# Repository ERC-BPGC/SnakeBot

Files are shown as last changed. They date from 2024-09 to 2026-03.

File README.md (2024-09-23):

# Project SnakeBot

### Overview 

SnakeBot is a modular, wheelless robot designed by the students of Electronics and Robotics Club. It uses a series of universal joints that provide 2 degrees of freedom (DOF) at each joint. The robot is actuated with the help of strings connected to servos, which rotate each module independently in its plane.

Our project aims to explore the locomotion patterns of snakes and apply them to robotics. Initially, we are focusing on straight-line motion and navigating in the 2D plane, but we aim to implement more advanced movements in the future, such as:

- Serpentine motion
- Sidewinding motion
- Lateral motion (Barell Roll)

The long-term goal of this project is to use the frictional properties of custom designed skin, allowing it to traverse various terrains and surfaces with minimal energy loss, just like biological snakes.

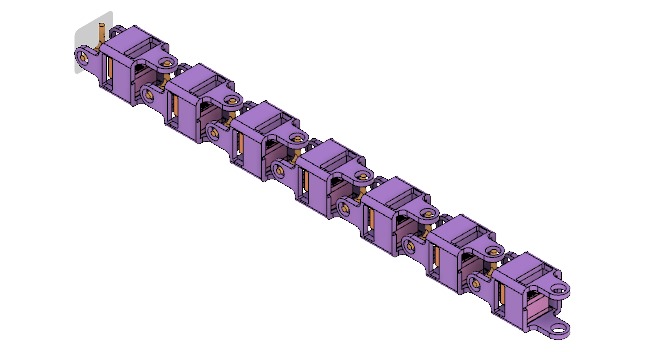
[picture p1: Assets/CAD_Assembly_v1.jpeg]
CAD Assembly


### Motion

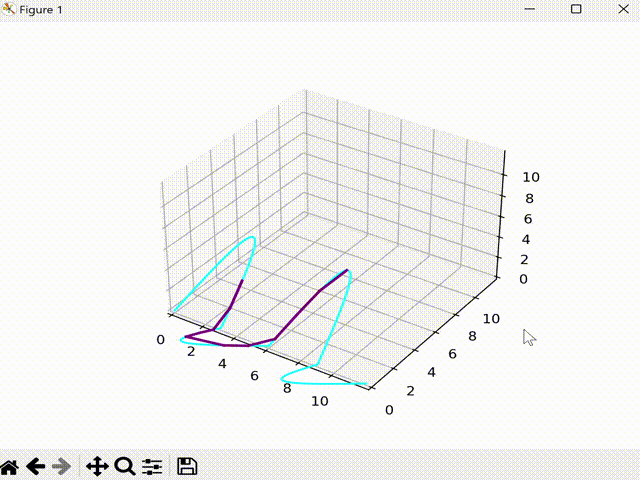
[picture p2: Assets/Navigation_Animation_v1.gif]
Modular motion in single axis


The fundamental concept behind this is using a sinosoidal wave in the x-y and y-z planes (phase shifted and one wave's amplitude encompassing another wave's) and then fitting the modular snakebot links within the bounds of this wave. This allows it to traverse in any direction based on how the wave evolves.

### PCB Designing

To give full modularity to the robot we have developed a modular, chainable PCB based on the RP2040 microcontroller. Each modular PCB consists of a power management circuit, LiPo battery connection, ability to add sensors like an IMU (MPU-6050), and controlling 2 servo motors per each module. We are planning to use serial communication between each module.

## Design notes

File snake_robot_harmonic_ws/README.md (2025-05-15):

# 🐍 Snake Robot MuJoCo Simulation Walkthrough

This guide provides a step-by-step walkthrough for setting up and running the **MuJoCo-based simulation** of a snake robot, located in your `snake_robot_harmonic_ws` workspace. This simulation is **standalone**—it does **not use ROS or Gazebo**—and is implemented purely using **MuJoCo and Python**.

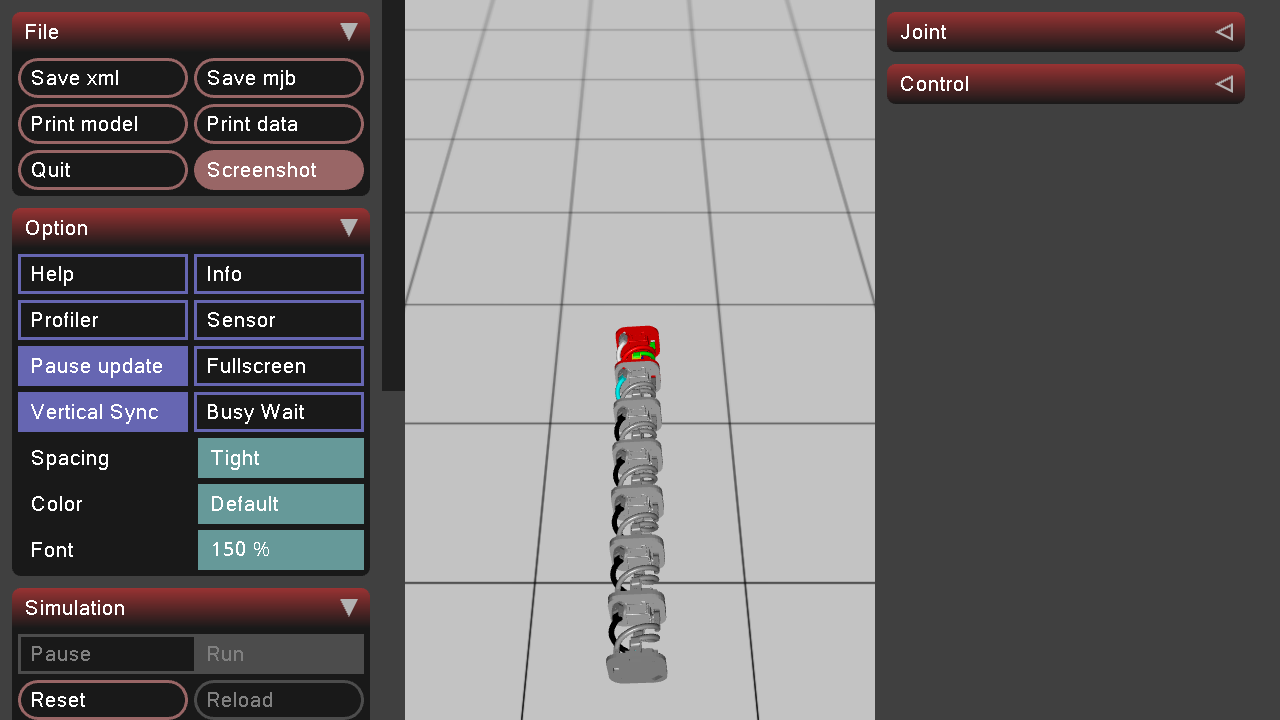
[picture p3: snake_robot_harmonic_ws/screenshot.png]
Snake Robot Model

---

## 📁 Project Structure Overview

```
snake_robot_harmonic_ws/
├── src/
│   └── SnakeBot/
│       ├── meshes/                                # STL files for the robot model
│       ├── ModelV2.xml                            # MuJoCo model of the snake robot
│       ├── scene.xml                              # MuJoCo scene (includes the robot and environment)
│       ├── nileshcode.py                          # Opens the MuJoCo model (no movement)
│       ├── multi_neuron_cpg_control.py            # Controller implementation (based on research)
│       ├── FLEXER_CPG_Sinusoidal_Control_Snake_Robot_Locomotion.py  # Another controller (FLEXER)
│       └── ...                                     # Other scripts and files
├── requirements.txt                                # Python dependencies
```

---

## 🧪 Setting Up the Python Virtual Environment

To ensure a clean and consistent development environment, we recommend using a virtual environment.

### Step 1: Navigate to the workspace

```bash
cd ~/snake_robot_harmonic_ws
```

### Step 2: Create and activate the virtual environment

```bash
python3 -m venv mujoco_env
source mujoco_env/bin/activate
```

> 💡 **Windows users**: Use `mujoco_env\Scripts\activate` instead.

### Step 3: Install required Python packages

Install dependencies listed in `requirements.txt`.  

> ⚠️ **Note**: This file may contain extra packages (e.g. ROS, CUDA, reinforcement learning libraries).  
> You can manually edit it to keep only the relevant packages for MuJoCo if needed.

```bash
pip install -r requirements.txt
```

---

## 🚀 Running the Simulation

After activating the virtual environment, you can run any of the following simulation scripts.

> ✅ **Important**: Make sure you're using the Python interpreter from the virtual environment.  
> If you're using an IDE or script launcher, confirm it uses the correct interpreter path.  
> You can also run scripts explicitly using the full path to the environment's Python:

```bash
./mujoco_env/bin/python path/to/script.py
```

### A. Launch MuJoCo Viewer (No Movement)

Opens the simulation in MuJoCo with the robot model loaded.

```bash
python src/SnakeBot/nileshcode.py
```

### B. Run Multi-Neuron CPG Controller

Based on a central pattern generator (CPG) research model.

```bash
python src/SnakeBot/multi_neuron_cpg_control.py
```
### 🧠 Multi-Neuron CPG Controller (Simulation)

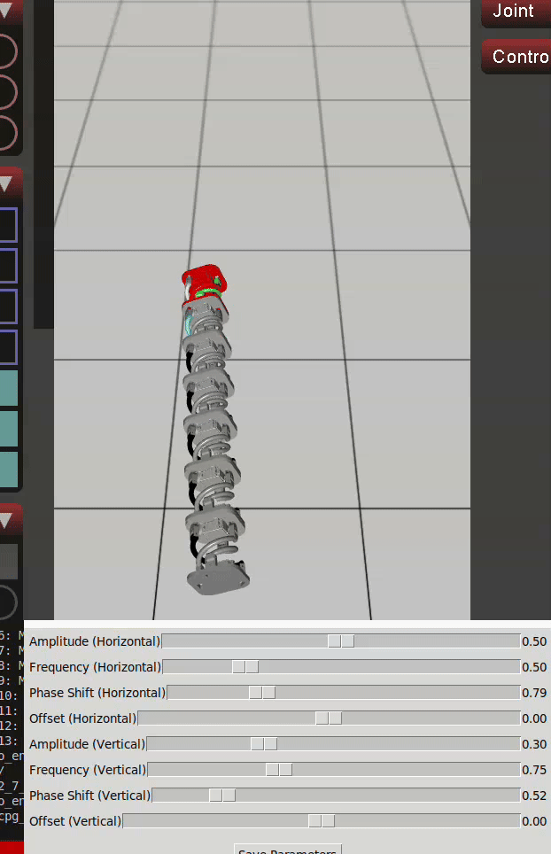
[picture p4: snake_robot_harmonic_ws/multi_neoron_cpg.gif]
Multi Neuron CPG Demo


### C. Run FLEXER CPG Sinusoidal Controller

Another research-based controller using FLEXER and sinusoidal inputs.

```bash
python src/SnakeBot/FLEXER_CPG_Sinusoidal_Control_Snake_Robot_Locomotion.py
```

### 🌊 FLEXER CPG Sinusoidal Controller (Simulation)

FLEXER CPG Demo
---

## 🧩 Notes and Recommendations

- ✅ Ensure that `scene.xml` and `ModelV2.xml` correctly reference STL files from the `meshes/` folder.
- 🧠 The control scripts implement algorithms from published research papers. You can customize the control parameters or logic for further experimentation.
- 💾 Consider creating a cleaned version of `requirements.txt` by running:

  ```bash
  pip freeze > requirements_clean.txt
  ```

---

## 📌 Summary

| Step | Description |
|---|---|
| ✅ 1 | Create & activate the `mujoco_env` virtual environment |
| ✅ 2 | Install dependencies from `requirements.txt` |
| ✅ 3 | Run desired control script (`nileshcode`, `multi_neuron_cpg_control`, or `FLEXER...`) |
| ✅ 4 | **Ensure you're using the correct Python interpreter from the virtual environment** (use full path if needed) |
| ✅ 5 | Validate STL and XML references for simulation correctness |

---

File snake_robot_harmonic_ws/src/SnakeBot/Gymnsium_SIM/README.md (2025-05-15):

Snake Robot Simulation Guide(Chatgpt for  simplification )

This is a guide for a Python program that makes a pretend snake robot move on your computer. It’s like a little game where the snake wiggles to move forward, and we see how good it is at moving. Let’s break it into tiny, easy bits!

What’s This Thing Do?

Imagine a toy snake made of blocks that can bend. This program:

Makes the snake wiggle like a real snake using wavy moves.

Runs little 10-second tests to see how far it goes.

Gives it points for moving forward fast.

Shows you pictures (graphs) of how well it did.

You can watch it wiggle in a window on your screen!

The Big Pieces

The program has 4 main parts—like ingredients in a recipe:

Tools (Imports): Stuff the program needs to work.

Snake World (SnakeEnv): Where the snake lives and moves.

Score Pictures (plot_rewards): Draws graphs of the snake’s points.

Start Button (main): Runs everything.

Let’s look at each one super simply.

1. Tools (Imports)

These are like helpers the program borrows:

gymnasium: Makes the pretend world.

MujocoEnv: Helps the snake move like it’s real.

numpy: Does math for us.

time: Slows things down so we can see.

matplotlib: Draws pictures of the scores.

2. Snake World (SnakeEnv)

This is the snake’s home. It’s split into little jobs.

Job lyk1: Starting Up (init)

Sets up the snake’s world.

Makes a big window (1280x720) to watch it.

Says the snake has 14 bendy parts (7 up-down, 7 side-side).

Keeps track of 41 things about the snake (like where it is and how fast it’s going).

Job 2: Looking at the Snake (_get_obs)

Takes a quick peek at the snake.

Writes down 41 numbers—like its spot, tilt, speed, and how its parts are bent.

Job 3: Moving a Tiny Bit (step)

Makes the snake wiggle once.

Picks wavy moves (like “big wiggle, fast wiggle”) using random numbers.

Example wiggle: “Bend up a little, then down, fast!”

Moves the snake a tiny step.

Checks if 10 seconds are up—if yes, it’s done.

Gives points for going forward.

Job 4: Starting Over (reset_model)

Puts the snake back to the start.

Picks new random wiggles for the next try.

Job 5: Picking Wiggles (_set_random_parameters)

Chooses random stuff for the wiggles:

How big the wiggle is.

How fast it wiggles.

Where the wiggle starts.

It’s like saying, “Wiggle big and slow this time!”

3. Score Pictures (plot_rewards)

Draws 2 pictures:

One shows all the points from each 10-second test.

One shows points for every tiny move in the last test.

Saves them as total_rewards_plot.png and last_episode_rewards_plot.png.

4. Start Button (main)

Turns on the snake world.

Keeps it going:

Moves the snake tiny bits.

Counts points.

After 10 seconds, starts over with new wiggles.

Prints stuff like “Episode 1: 50 points!”

When you stop it (close the window), it shows the pictures.

How It Works, Step by Step

Start: The program loads the snake and opens a window.

Wiggle: The snake moves with random wiggles for 10 seconds.

Score: It gets points for going forward.

Repeat: Starts over with new wiggles.

Finish: You close it, and it shows score pictures.

Easy Example

Think of the snake like a toy car with bendy parts:

You push “start,” and it wiggles forward.

If it goes far, it gets lots of points!

Every 10 seconds, you try a new wiggle to see if it’s better.

How to Play With It

Get Ready: Make sure you have the tools (like gymnasium) on your computer.

Find the Snake: Tell the program where the snake’s file is.

Run It: Start the program—watch the snake wiggle!

Stop It: Close the window when you’re done.

See Scores: Look at the pictures it saves.

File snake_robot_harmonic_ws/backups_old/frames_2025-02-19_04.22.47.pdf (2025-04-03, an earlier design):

view_frames Result

Recorded at time: 1739919167.9612372

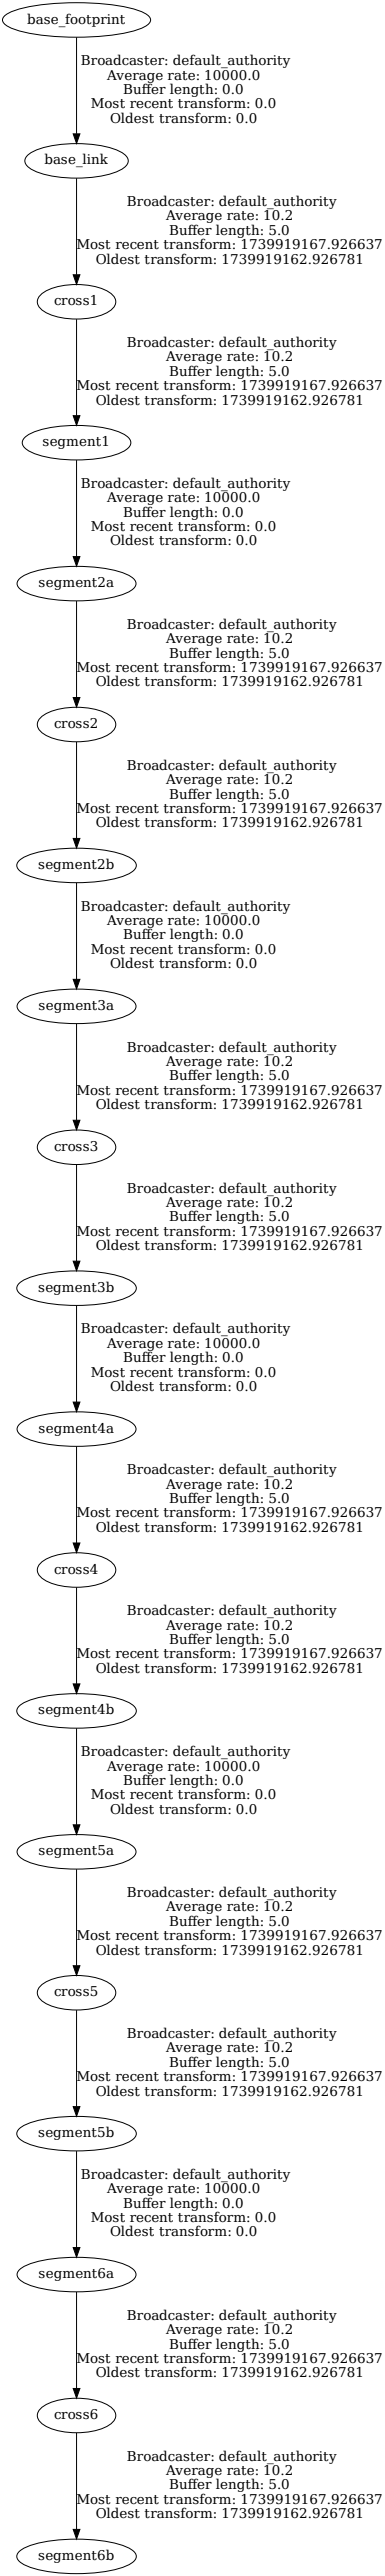
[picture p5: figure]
cross1; segment1; Broadcaster: default_authority Average rate: 10.2 Buffer length: 5.0 Most recent transform: 1739919167.926637 Oldest transform: 1739919162.926781; segment2a; Broadcaster: default_authority Average rate: 10000.0 Buffer length: 0.0 Most recent transform: 0.0 Oldest transform: 0.0; base_link; segment5a; cross5; segment5b; segment4b; cross6; segment6b; segment6a; base_footprint; cross2; segment2b; segment3a; cross3; segment3b; segment4a; cross4

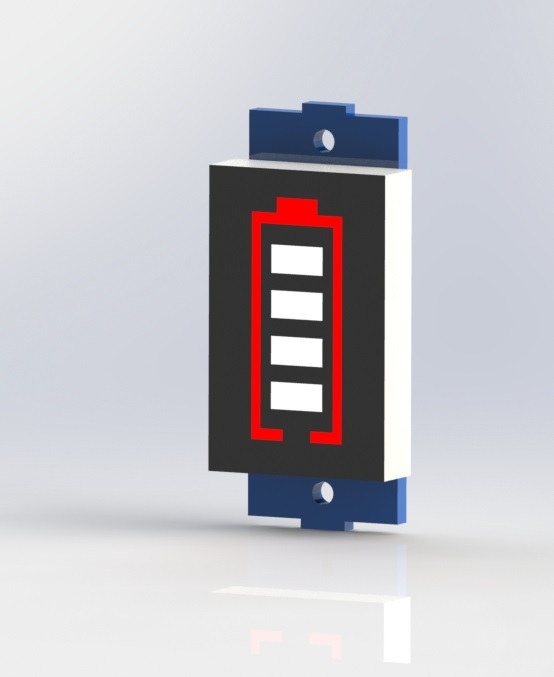
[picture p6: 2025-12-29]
mech/new/18650-li-ion-battery-capacity-indicator-module-1.snapshot.1/Lithium Battery Capacity Indicator Module/Lithium Battery Capacity Indicator Module.JPG

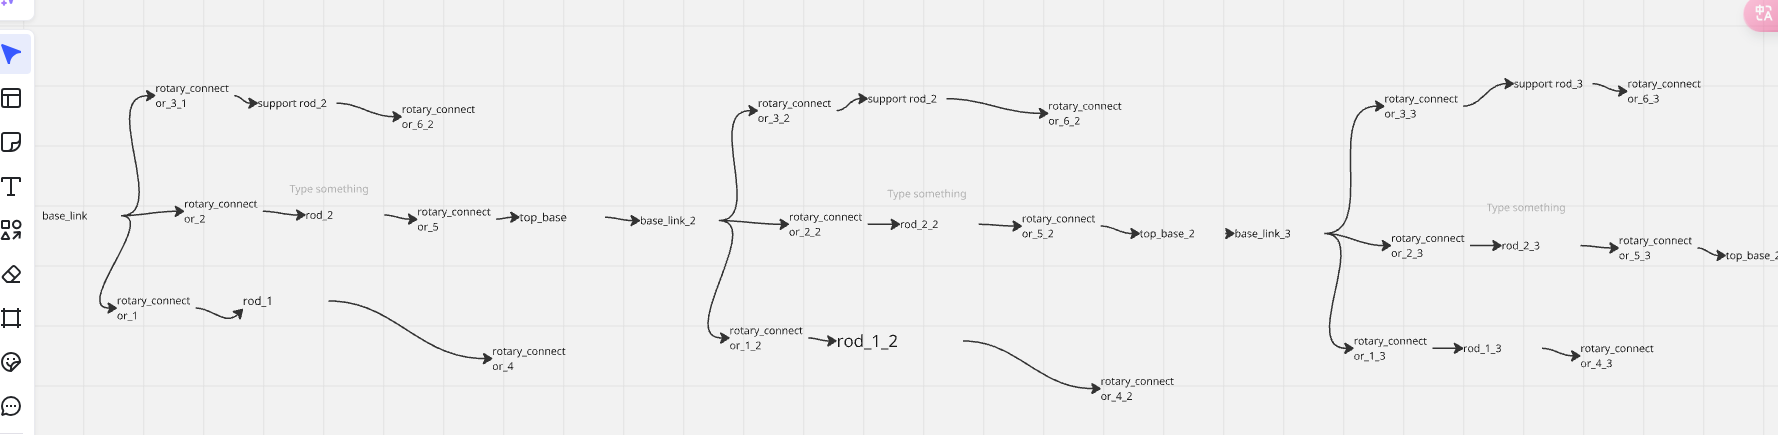
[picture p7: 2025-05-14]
snake_robot_harmonic_ws/src/SnakeBot/Gymnsium_SIM _backup_working_basic/my_env/robot_model/meshes/Opera Snapshot_2025-04-20_045715_miro.com.png

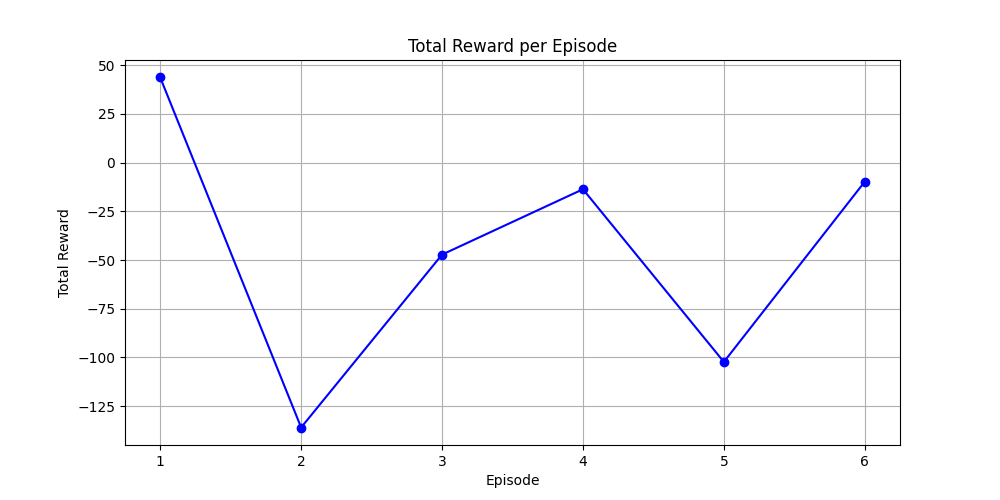
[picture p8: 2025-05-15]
snake_robot_harmonic_ws/src/SnakeBot/Gymnsium_SIM/my_env/total_rewards_plot.png

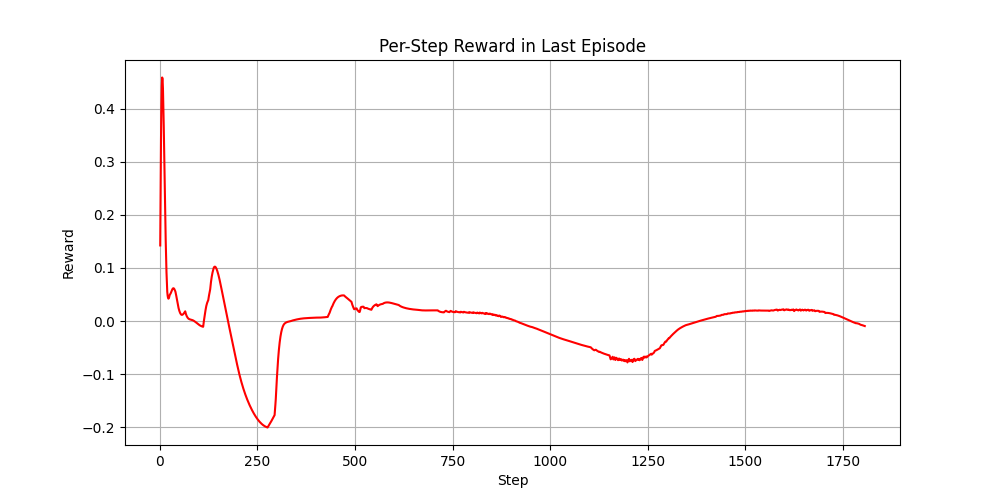
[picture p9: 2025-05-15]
snake_robot_harmonic_ws/src/SnakeBot/Gymnsium_SIM/my_env/last_episode_rewards_plot.png

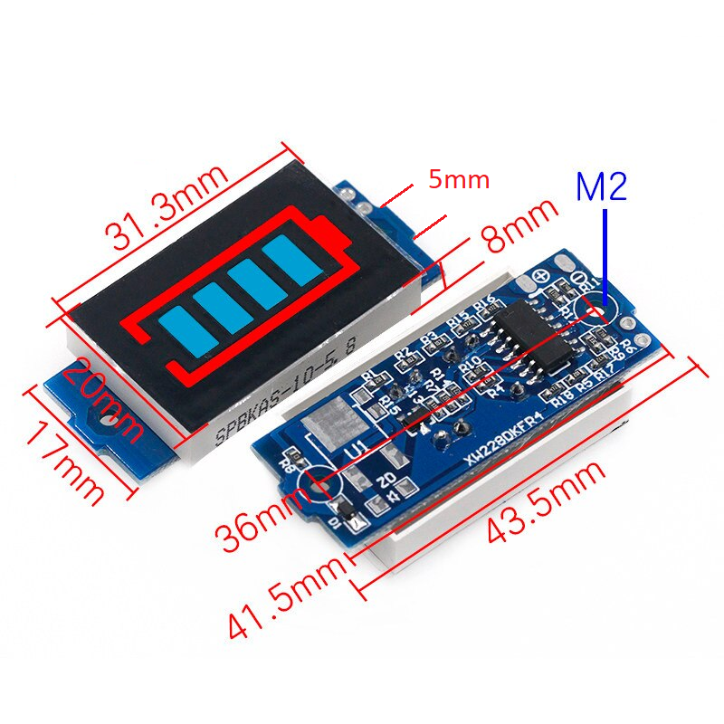
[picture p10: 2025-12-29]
mech/new/18650-li-ion-battery-capacity-indicator-module-1.snapshot.1/Lithium Battery Capacity Indicator Module/Lithium Battery Capacity Indicator Module dimentions.png

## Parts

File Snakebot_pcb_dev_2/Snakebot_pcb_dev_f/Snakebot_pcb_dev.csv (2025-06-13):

Reference | Value | Datasheet | Footprint | Qty | DNP
C1 | 22uF | ~ | Capacitor_SMD:C_0603_1608Metric_Pad1.08x0.95mm_HandSolder | 1
C2 | 0.1uF | ~ | Capacitor_SMD:C_0603_1608Metric_Pad1.08x0.95mm_HandSolder | 1
C3 | 1uF | ~ | Capacitor_SMD:C_0805_2012Metric_Pad1.18x1.45mm_HandSolder | 1
C4 | 10uF | ~ | Capacitor_SMD:C_0805_2012Metric_Pad1.18x1.45mm_HandSolder | 1
C5 | 10uF | ~ | Capacitor_SMD:C_0805_2012Metric_Pad1.18x1.45mm_HandSolder | 1
C6 | 0.1uF | ~ | Capacitor_SMD:C_0603_1608Metric_Pad1.08x0.95mm_HandSolder | 1
C7 | 0.1uF | ~ | Capacitor_SMD:C_0603_1608Metric_Pad1.08x0.95mm_HandSolder | 1
C8 | 22uF | ~ | Capacitor_SMD:C_0603_1608Metric_Pad1.08x0.95mm_HandSolder | 1
C9 | 0.1uF | ~ | Capacitor_SMD:C_0603_1608Metric_Pad1.08x0.95mm_HandSolder | 1
C10 | 22uF | ~ | Capacitor_SMD:C_0603_1608Metric_Pad1.08x0.95mm_HandSolder | 1
C11 | 1uF | ~ | Capacitor_SMD:C_0805_2012Metric_Pad1.18x1.45mm_HandSolder | 1
C12 | 1uF | ~ | Capacitor_SMD:C_0805_2012Metric_Pad1.18x1.45mm_HandSolder | 1
C13 | 0.1uF | ~ | Capacitor_SMD:C_0603_1608Metric_Pad1.08x0.95mm_HandSolder | 1
C14 | 0.1uF | ~ | Capacitor_SMD:C_0603_1608Metric_Pad1.08x0.95mm_HandSolder | 1
C15 | 0.1uF | ~ | Capacitor_SMD:C_0603_1608Metric_Pad1.08x0.95mm_HandSolder | 1
C16 | 220pF | ~ | Capacitor_SMD:C_0603_1608Metric_Pad1.08x0.95mm_HandSolder | 1
D1 | LED | ~ | LED_SMD:LED_0805_2012Metric_Pad1.15x1.40mm_HandSolder | 1
D2 | LED | ~ | LED_SMD:LED_0805_2012Metric_Pad1.15x1.40mm_HandSolder | 1
D3 | LED | ~ | LED_SMD:LED_0805_2012Metric_Pad1.15x1.40mm_HandSolder | 1
J1 | Conn_01x04_Socket | ~ | Connector_JST:JST_EH_S4B-EH_1x04_P2.50mm_Horizontal | 1
J2 | Conn_01x02_Socket | ~ | Connector_JST:JST_EH_S2B-EH_1x02_P2.50mm_Horizontal | 1
J3 | Conn_01x03_Socket | ~ | Connector_JST:JST_EH_B3B-EH-A_1x03_P2.50mm_Vertical | 1
J4 | Conn_01x03_Socket | ~ | Connector_JST:JST_EH_B3B-EH-A_1x03_P2.50mm_Vertical | 1
J5 | Conn_01x02_Socket | ~ | Connector_JST:JST_EH_S2B-EH_1x02_P2.50mm_Horizontal | 1
J6 | Conn_01x02_Socket | ~ | Connector_JST:JST_EH_S2B-EH_1x02_P2.50mm_Horizontal | 1
J7 | Conn_01x08_Socket | ~ | Connector_JST:JST_EH_B8B-EH-A_1x08_P2.50mm_Vertical | 1
J8 | Conn_01x08_Socket | ~ | Connector_JST:JST_EH_B8B-EH-A_1x08_P2.50mm_Vertical | 1
L1 | 6.8uH | ~ | Inductor_SMD:L_Bourns_SRN8040TA | 1
R1 | 10k | ~ | Resistor_SMD:R_0603_1608Metric_Pad0.98x0.95mm_HandSolder | 1
R2 | 1K | ~ | Resistor_SMD:R_0603_1608Metric_Pad0.98x0.95mm_HandSolder | 1
R3 | 1K | ~ | Resistor_SMD:R_0603_1608Metric_Pad0.98x0.95mm_HandSolder | 1
R4 | 1K | ~ | Resistor_SMD:R_0603_1608Metric_Pad0.98x0.95mm_HandSolder | 1
R5 | 50m | ~ | Resistor_SMD:R_0603_1608Metric_Pad0.98x0.95mm_HandSolder | 1
R6 | 10k | ~ | Resistor_SMD:R_0603_1608Metric_Pad0.98x0.95mm_HandSolder | 1
R7 | 10k | ~ | Resistor_SMD:R_0603_1608Metric_Pad0.98x0.95mm_HandSolder | 1
R8 | 100k | ~ | Resistor_SMD:R_0805_2012Metric_Pad1.20x1.40mm_HandSolder | 1
R9 | 4.7k | ~ | Resistor_SMD:R_0603_1608Metric_Pad0.98x0.95mm_HandSolder | 1
R10 | 4.7k | ~ | Resistor_SMD:R_0603_1608Metric_Pad0.98x0.95mm_HandSolder | 1
SW1 | SW_Push | ~ | Button_Switch_SMD:SW_Push_1P1T_NO_CK_KSC6xxJ | 1
SW2 | SW_Push | ~ | Button_Switch_SMD:SW_Push_1P1T_NO_CK_KSC6xxJ | 1
SW3 | SW_SPDT | ~ | Button_Switch_SMD:SW_SPDT_CK_JS102011SAQN | 1
U1 | ESP32-WROOM-32E | https://www.espressif.com/sites/default/files/documentation/esp32-wroom-32e_esp32-wroom-32ue_datasheet_en.pdf | RF_Module:ESP32-WROOM-32D | 1
U2 | AMS1117-3.3 | http://www.advanced-monolithic.com/pdf/ds1117.pdf | Package_TO_SOT_SMD:SOT-223-3_TabPin2 | 1
U3 | MP2615GQ-P | MP2615GQ-P | MP2615:QFN-3x3_MP2615_MNP | 1
U4 | MPU-6050 | https://invensense.tdk.com/wp-content/uploads/2015/02/MPU-6000-Datasheet1.pdf | Sensor_Motion:InvenSense_QFN-24_4x4mm_P0.5mm | 1

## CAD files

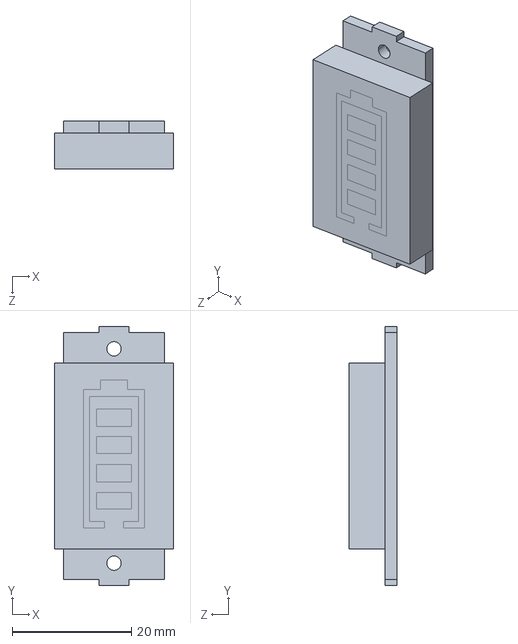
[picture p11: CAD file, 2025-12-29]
mech/new/18650-li-ion-battery-capacity-indicator-module-1.snapshot.1/Lithium Battery Capacity Indicator Module/Lithium Battery Capacity Indicator Module.STEP
20.0 x 43.5 x 8.00 mm

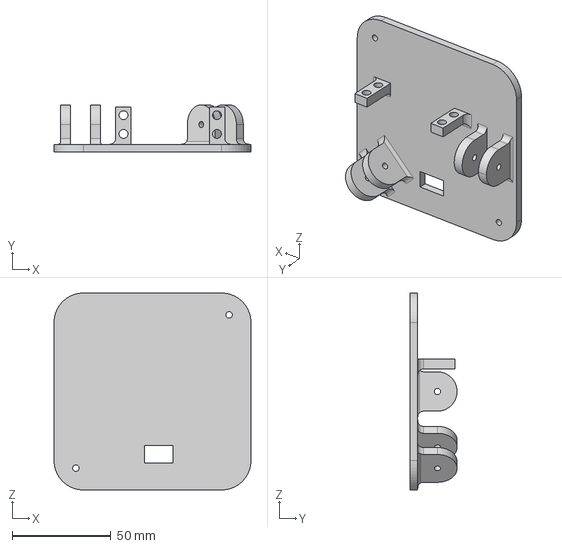
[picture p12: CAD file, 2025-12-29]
mech/new/Component1.step
100.0 x 24.0 x 100.0 mm

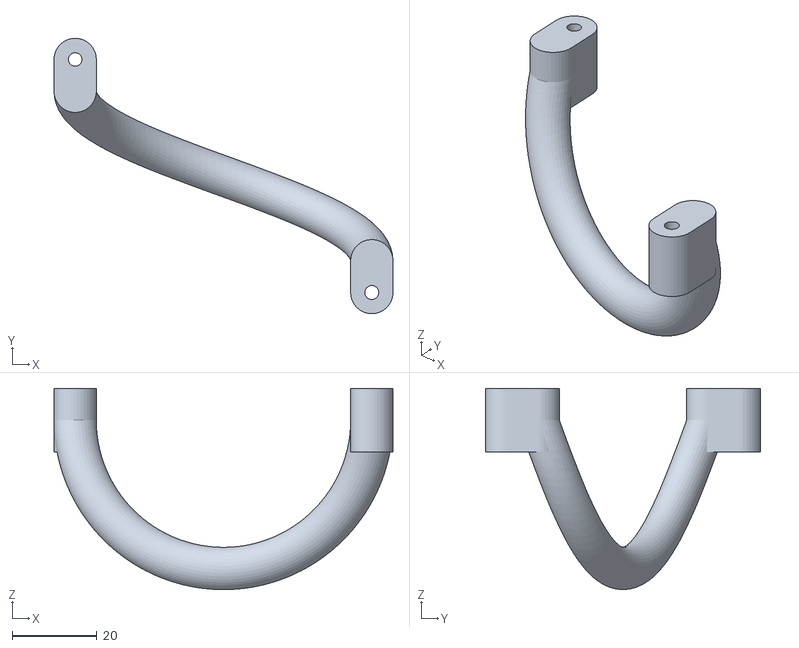
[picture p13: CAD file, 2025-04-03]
snake_robot_harmonic_ws/src/ros_gz_example_description/models/snakebot/meshes/rod.stl
80.0 x 65.0 x 47.5

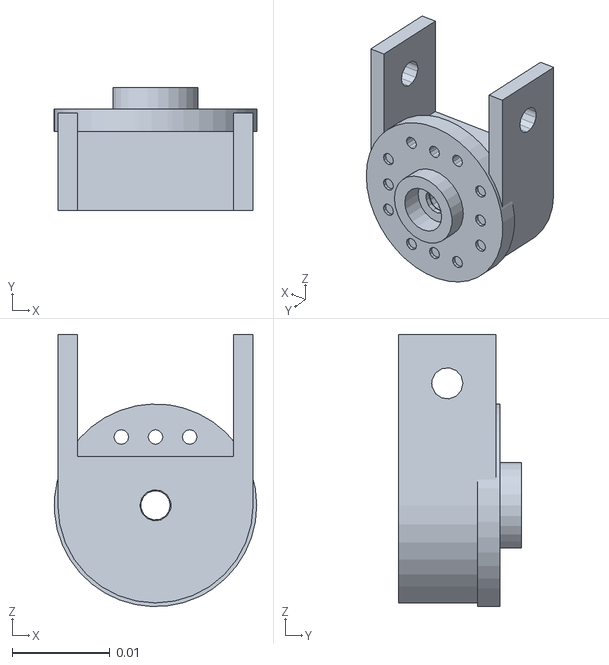
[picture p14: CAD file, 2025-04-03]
snake_robot_harmonic_ws/src/SnakeBot/Gymnsium_SIM _backup_working_basic/my_env/robot_model/meshes/rotary_connector_1.STL
0.0207 x 0.0126 x 0.0279

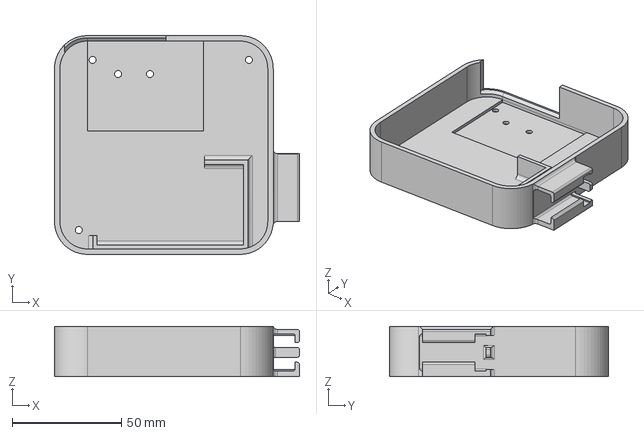
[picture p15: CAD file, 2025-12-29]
mech/new/dabba_sarn.step
112.0 x 100.0 x 23.0 mm

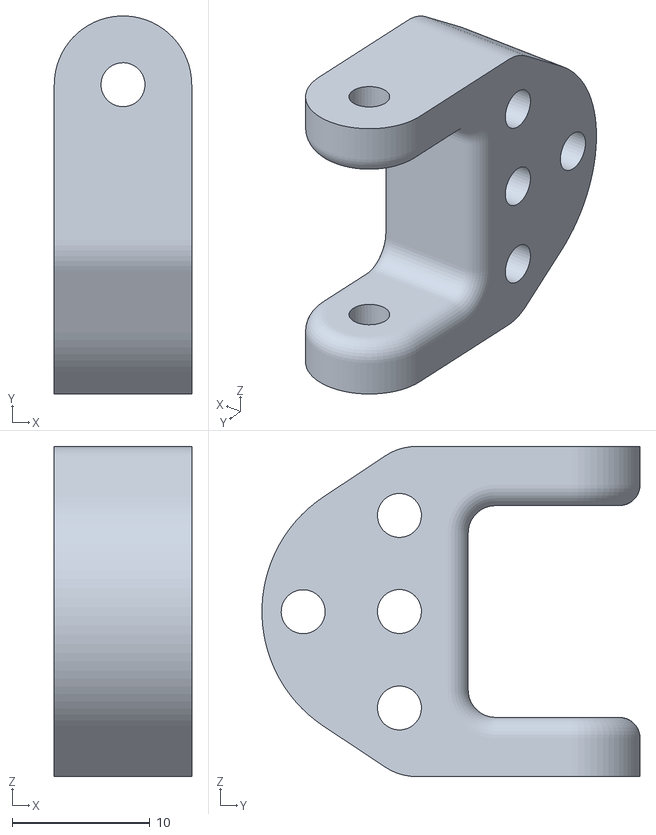
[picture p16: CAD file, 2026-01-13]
Mujoco/chintu.stl
10.0 x 27.5 x 24.0

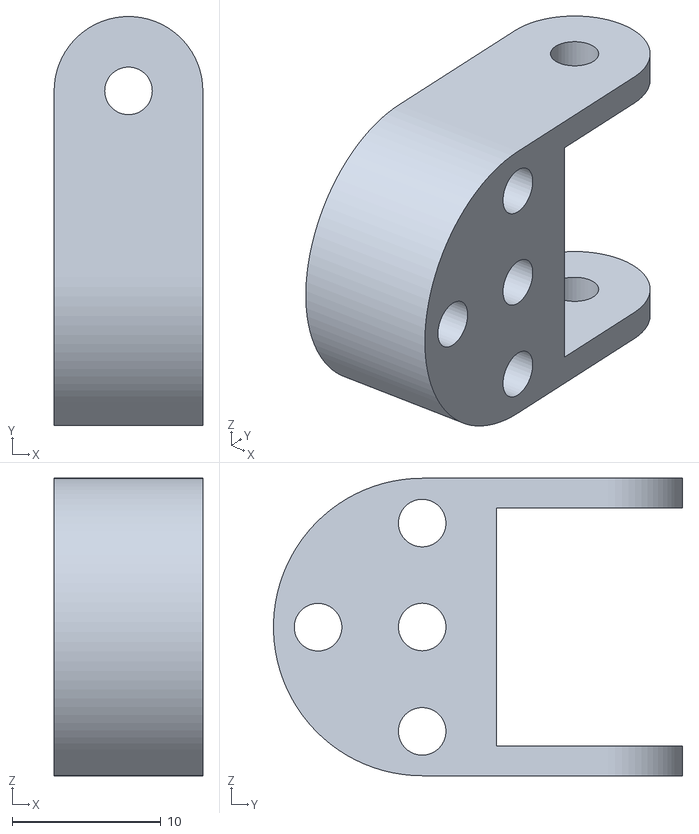
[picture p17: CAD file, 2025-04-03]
snake_robot_harmonic_ws/src/ros_gz_example_description/models/snakebot/meshes/rotary.stl
10.0 x 27.5 x 20.0

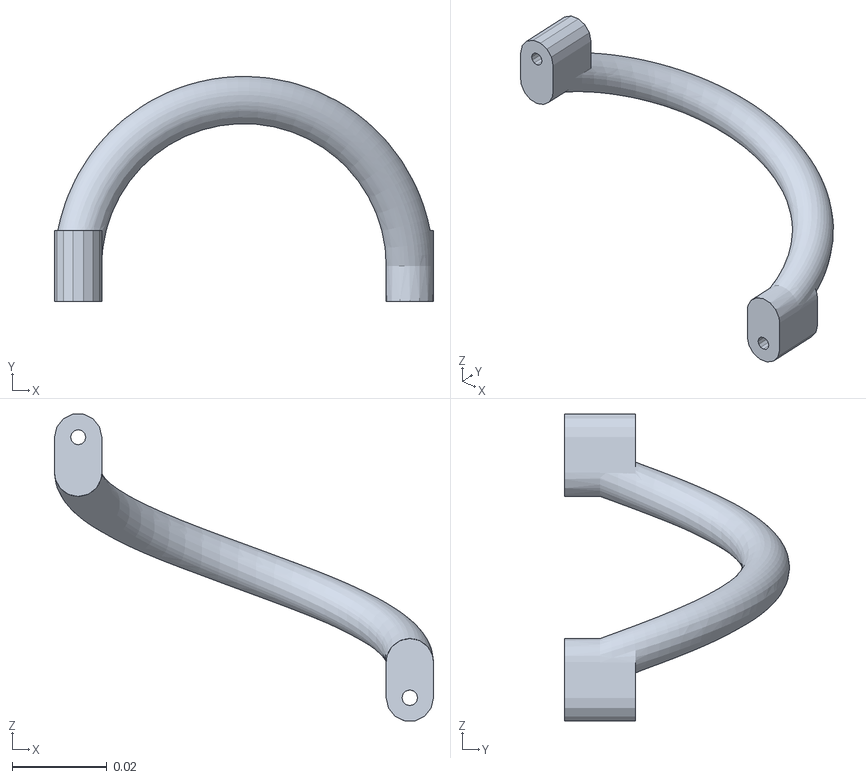
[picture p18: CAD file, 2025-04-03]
snake_robot_harmonic_ws/src/SnakeBot/Gymnsium_SIM _backup_working_basic/my_env/robot_model/meshes/rod_1.STL
0.08 x 0.0475 x 0.0648

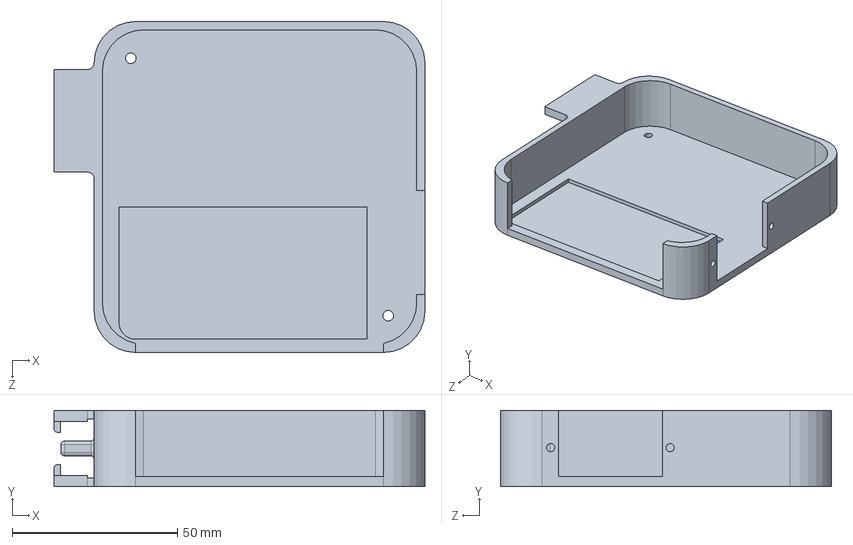
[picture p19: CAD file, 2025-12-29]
mech/new/pcb_holder_v1.SLDPRT
112.1 x 23.0 x 100.0 mm

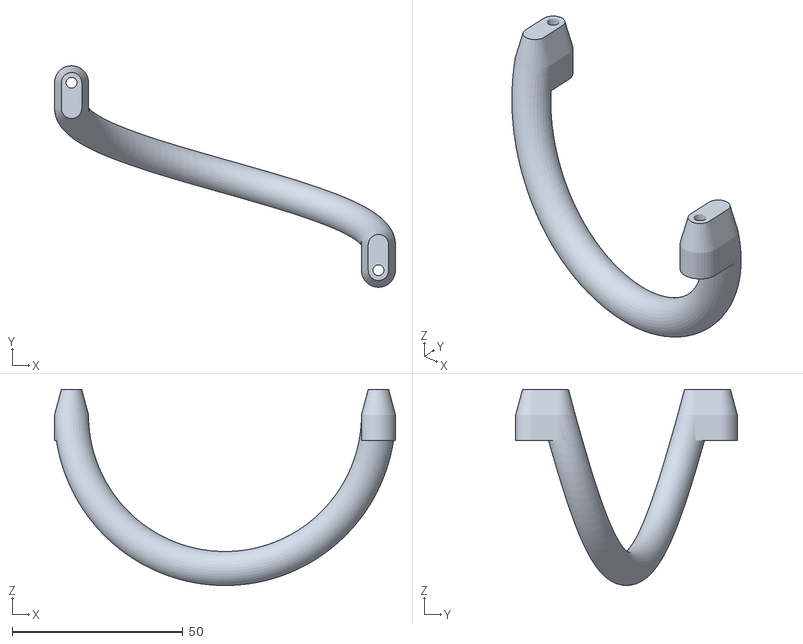
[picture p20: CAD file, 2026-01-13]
Mujoco/danda support.stl
100.0 x 65.0 x 57.5

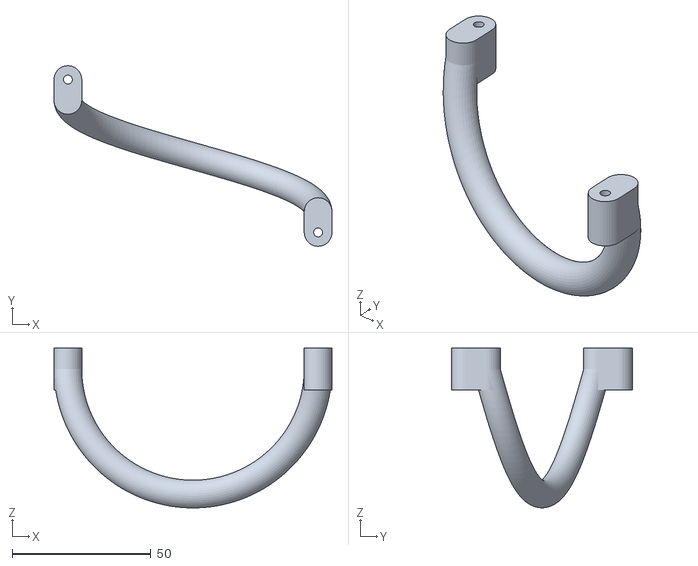
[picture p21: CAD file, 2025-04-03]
snake_robot_harmonic_ws/src/ros_gz_example_description/models/snakebot/meshes/rodsupport.stl
100.0 x 65.0 x 57.5

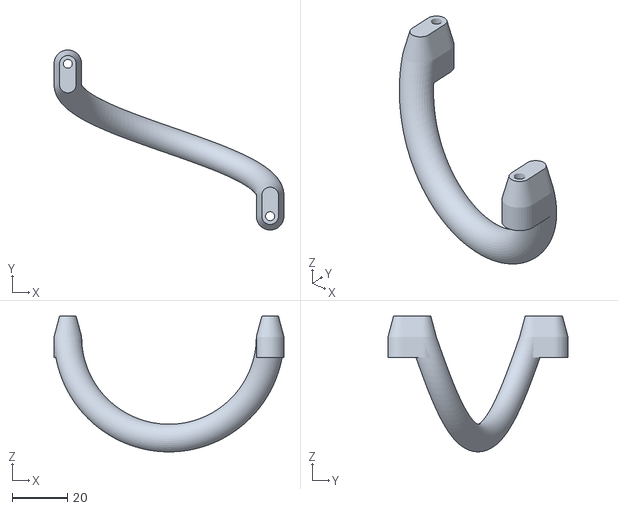
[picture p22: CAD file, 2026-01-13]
Mujoco/danda.stl
83.0 x 65.0 x 49.0

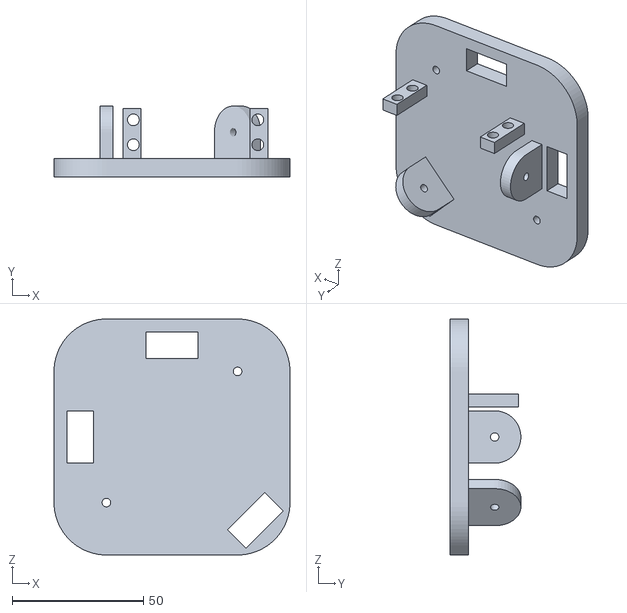
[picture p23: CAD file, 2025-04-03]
snake_robot_harmonic_ws/src/ros_gz_example_description/models/snakebot/meshes/snake_base.stl
90.0 x 27.0 x 90.0

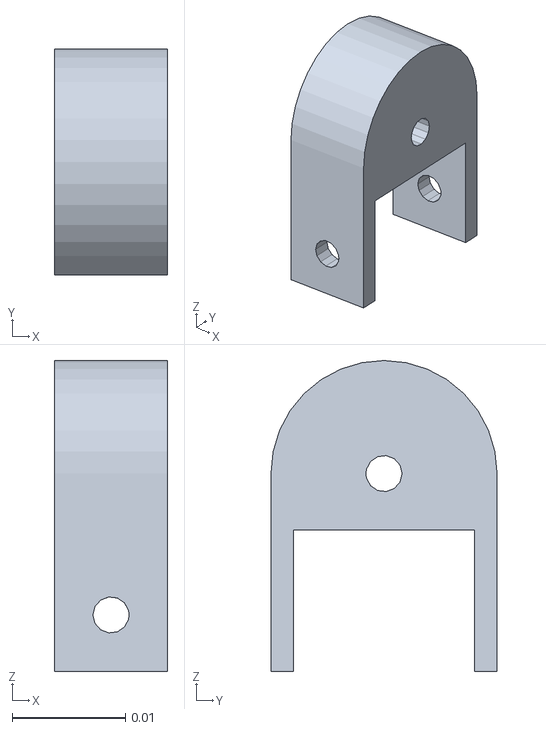
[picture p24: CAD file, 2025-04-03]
snake_robot_harmonic_ws/src/SnakeBot/Gymnsium_SIM _backup_working_basic/my_env/robot_model/meshes/rotary_connector_5.STL
0.01 x 0.02 x 0.0275

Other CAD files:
Mujoco/snakebot module.stl
snake_robot_harmonic_ws/src/SnakeBot/Gymnsium_SIM _backup_working_basic/my_env/robot_model/meshes/rod_2.STL
snake_robot_harmonic_ws/src/ros_gz_example_description/models/snakebot/meshes/cross.stl
snake_robot_harmonic_ws/src/SnakeBot/Gymnsium_SIM _backup_working_basic/my_env/robot_model/meshes/top_base.STL
mech/new/18650-li-ion-battery-capacity-indicator-module-1.snapshot.1/Lithium Battery Capacity Indicator Module/Lithium Battery Capacity Indicator Module.SLDPRT
mech/new/new.f3d
mech/old/snake base.3mf
mech/old/snake_module.stl
mech/old/uv joint v1.stl
snake_robot_harmonic_ws/src/SnakeBot/Gymnsium_SIM _backup_working_basic/my_env/robot_model/meshes/base_link.STL
snake_robot_harmonic_ws/src/SnakeBot/Gymnsium_SIM _backup_working_basic/my_env/robot_model/meshes/rotary_connector_2.STL
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

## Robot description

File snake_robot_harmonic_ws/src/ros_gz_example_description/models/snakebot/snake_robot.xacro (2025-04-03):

<?xml version="1.0"?>
<robot name="snake_robot" xmlns:xacro="http://ros.org/wiki/xacro">

  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
   <xacro:property name="segment_mass" value="0.0525" /> 
 
    <xacro:property name="cross_mass" value="0.005" />


  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
  <link name="base_footprint"> </link>
<joint name="body link joint" type="fixed">
<parent link="base_footprint"/>
<child link="base_link"/>
</joint>
  <link name="base_link">
    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
    <inertial>
      <mass value="${segment_mass}" />
      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
    </inertial>
  </link>

 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
  <xacro:macro name="cross" params="no">
    <link name="cross${no}">
      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
      <inertial>
        <mass value="${cross_mass}" />
        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
      </inertial>
    </link>
  </xacro:macro>

  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
  <xacro:macro name="segment_vertical" params="no">
    <link name="segment${no}a">
      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
      <inertial>
        <mass value="${segment_mass}" />
        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
      </inertial>
    </link>
  </xacro:macro>

  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
  <xacro:macro name="segment_horizontal" params="no">
    <link name="segment${no}b">
      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
      <inertial>
        <mass value="${segment_mass}" />
        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
      </inertial>
    </link>
    <link name="servo${no}">
  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
  <inertial>
    <mass value="0.05" />
    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
  </inertial>
</link>

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
<joint name="servo_joint${no}" type="fixed">
  <parent link="segment${no}b" />
  <child link="servo${no}" />
  <origin rpy="1.57 0 3.14" xyz="0.0 -0.55 0.0" /> 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
</joint>
  </xacro:macro>

  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
  <xacro:macro name="joint_horizontal" params="no">
    <joint name="joint${2 * no - 1}" type="revolute">
      <parent link="cross${no}" />
      <child link="segment${no}b" />
      <origin rpy="0 0 0" xyz="0 0 0" />
      <axis xyz="0 0 1" />
      <limit effort="100" lower="-1.57" upper="1.57" velocity="1" />
    </joint>
  </xacro:macro>

  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
  <xacro:macro name="joint_vertical" params="no">
    <joint name="joint${2 * no}" type="revolute">
      <parent link="segment${no}a" />
      <child link="cross${no}" />
      <origin rpy="0 0 0" xyz="0 -0.522 0" />
      <axis xyz="1 0 0" />
      <limit effort="100" lower="-1.57" upper="1.57" velocity="1" />
    </joint>
  </xacro:macro>

  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
  <xacro:macro name="joint_fixed" params="no">
    <joint name="joint_fix_mod_${no}" type="fixed">
      <parent link="segment${no -1}b" />
      <child link="segment${no}a" />
      <origin rpy="0 0 0" xyz="0 -0.60 0" />
    </joint>
  </xacro:macro>

  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
  <xacro:macro name="module" params="no">
    <xacro:segment_vertical no="${no}"></xacro:segment_vertical>
    <xacro:joint_fixed no="${no}"></xacro:joint_fixed>
    <xacro:cross no="${no}"></xacro:cross>
    <xacro:segment_horizontal no="${no}"></xacro:segment_horizontal>
    <xacro:joint_horizontal no="${no}"></xacro:joint_horizontal>
    <xacro:joint_vertical no="${no}"></xacro:joint_vertical>
   
  </xacro:macro>
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
  <link name="cross1">
    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
    <inertial>
      <mass value="${cross_mass}" />
      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
    </inertial>
  </link>

  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
  <link name="segment1">
    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
    <inertial>
      <mass value="${segment_mass}" />
      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
    </inertial>
  </link>

  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
  <joint name="joint2" type="revolute">
    <parent link="base_link" />
    <child link="cross1" />
    <origin rpy="0 0 0" xyz="0 0 0" />
    <axis xyz="1 0 0" />
    <limit effort="100" lower="-1.57" upper="1.57" velocity="1" />
  </joint>

  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
  <joint name="joint1" type="revolute">
    <parent link="cross1" />
    <child link="segment1" />
    <origin rpy="0 0 0" xyz="0 0 0" />
    <axis xyz="0 0 1" />
    <limit effort="100" lower="-1.57" upper="1.57" velocity="1" />
  </joint>

  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
  <xacro:segment_vertical no="2"></xacro:segment_vertical>

  <joint name="joint_fix_mod_2" type="fixed">
    <parent link="segment1" />
    <child link="segment2a" />
    <origin rpy="0 0 0" xyz="0 -0.60 0" />
  </joint>

  <xacro:cross no="2"></xacro:cross>
  <xacro:segment_horizontal no="2"></xacro:segment_horizontal>
  <xacro:joint_horizontal no="2"></xacro:joint_horizontal>
  <xacro:joint_vertical no="2"></xacro:joint_vertical>

  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
  <xacro:module no="3"></xacro:module>
  <xacro:module no="4"></xacro:module>
  <xacro:module no="5"></xacro:module>
  <xacro:module no="6"></xacro:module>
<xacro:include filename="$(find ros_gz_example_description)/models/snakebot/robot.gazebo" /> |
</robot>

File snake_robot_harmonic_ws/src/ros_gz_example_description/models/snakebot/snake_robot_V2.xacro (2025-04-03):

<?xml version="1.0"?>
<robot name="snake_robot" xmlns:xacro="http://ros.org/wiki/xacro">

  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
  <xacro:property name="scale_factor" value="0.001"/>

  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
  <xacro:property name="mesh_base" value="package://ros_gz_example_description/models/snakebot/meshes/snake_base.stl" />
  <xacro:property name="mesh_rotary" value="package://ros_gz_example_description/models/snakebot/meshes/rotary.stl" />
     <xacro:property name="mesh_rod_short" value="package://ros_gz_example_description/models/snakebot/meshes/rod.stl" />
     <xacro:property name="mesh_rod_long" value="package://ros_gz_example_description/models/snakebot/meshes/rodsupport.stl" />

  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
  <link name="base_footprint">
    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
  </link>

  <joint name="body_link_joint" type="fixed">
    <parent link="base_footprint"/>
    <child link="base_link"/>
  </joint>

  <link name="base_link">
    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
    <inertial>
      <mass value="${0.0525}" />
      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
    </inertial>
  </link>

  <joint name="joint_base_to_rotary_r_1" type="revolute">
    <parent link="base_link"/>
    <child link="rotary_link_r_1"/>
    <origin rpy="0 -0.7853975 0" xyz="${ 5 * scale_factor} ${-10 * scale_factor} ${5 * scale_factor} "/>
    <limit effort="100" lower="-1.57" upper="1.57" velocity="1" />
  </joint>

  <link name="rotary_link_r_1">
    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
    <inertial>
      <mass value="${0.0525}" />
      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
    </inertial>
  </link>

  <joint name="joint_base_to_rotary_p_1" type="revolute">
    <parent link="base_link"/>
    <child link="rotary_link_p_1"/>
    <origin rpy="0 0 0" xyz="${ -69 * scale_factor} ${-10 * scale_factor} ${0 * scale_factor} "/>
    <limit effort="100" lower="-1.57" upper="1.57" velocity="1" />
  </joint>

  <link name="rotary_link_p_1">
    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
    <inertial>
      <mass value="${0.0525}" />
      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
    </inertial>
  </link>

   <joint name="joint_base_to_rotary_y_1" type="revolute">
    <parent link="base_link"/>
    <child link="rotary_link_y_1"/>
    <origin rpy="0 -1.57 0" xyz="${ -0 * scale_factor} ${-10 * scale_factor} ${-69 * scale_factor} "/>
    <limit effort="100" lower="-1.57" upper="1.57" velocity="1" />
  </joint>

  <link name="rotary_link_y_1">
    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
    <inertial>
      <mass value="${0.0525}" />
      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
    </inertial>
  </link>

  <joint name="joint_rotary_to_rod_y_1" type="revolute">
    <parent link="rotary_link_y_1"/>
    <child link="rod_link_y_1"/>
    <axis xyz="0 0 1"/> 
    <origin rpy="0 0 0" xyz="${ 35 * scale_factor} ${-12.5 * scale_factor} ${-0 * scale_factor} "/>
    <limit effort="100" lower="-1.57" upper="1.57" velocity="1"/>
  </joint>

  <link name="rod_link_y_1">
    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
    <inertial>
      <mass value="${0.0525}" />
      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
    </inertial>
  </link>

  <joint name="joint_rotary_to_rod_p_1" type="revolute">
    <parent link="rotary_link_p_1"/>
    <child link="rod_link_p_1"/>
    <axis xyz="0 0 1"/> 
    <origin rpy="0 0 0" xyz="${ 35 * scale_factor} ${-12.5 * scale_factor} ${-0 * scale_factor} "/>
    <limit effort="100" lower="-1.57" upper="1.57" velocity="1" />
  </joint>

  <link name="rod_link_p_1">
    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
    <inertial>
      <mass value="${0.0525}" />
      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
    </inertial>
  </link>

 <joint name="joint_rotary_to_rod_r_1" type="revolute">
    <parent link="rotary_link_r_1"/>
    <child link="rod_link_r_1"/>
    <axis xyz="0 0 1"/> 
    <origin rpy="0 3.14 0" xyz="${ 35 * scale_factor} ${-12.5 * scale_factor} ${-0 * scale_factor} "/>
    <limit effort="100" lower="-1.57" upper="1.57" velocity="1" />
  </joint>

  <link name="rod_link_r_1">
    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
    <inertial>
      <mass value="${0.0525}" />
      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
    </inertial>
  </link>


   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
   <joint name="joint_rotary_to_rod_y_2" type="revolute">
    <parent link="rod_link_y_1"/>
    <child link="rotary_link_y_2"/>
    <axis xyz="0 0 1"/> 
    <origin rpy="0 0 0" xyz="${ 70* scale_factor} ${-55 * scale_factor} ${-0 * scale_factor} "/>
    <limit effort="100" lower="-1.57" upper="1.57" velocity="1" />

  </joint>

   <link name="rotary_link_y_2">
    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
    <inertial>
      <mass value="${0.0525}" />
      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
    </inertial>
  </link>

   <joint name="joint_rotary_to_rod_p_2" type="revolute">
    <parent link="rod_link_p_1"/>
    <child link="rotary_link_p_2"/>
    <axis xyz="0 0 1"/> 
    <origin rpy="0 0 0" xyz="${ 70* scale_factor} ${-55 * scale_factor} ${-0 * scale_factor} "/>
    <limit effort="100" lower="-1.57" upper="1.57" velocity="1" />
  </joint>

   <link name="rotary_link_p_2">
    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
    <inertial>
      <mass value="${0.0525}" />
      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
    </inertial>
  </link>

  <joint name="joint_rotary_to_rod_r_2" type="revolute">
    <parent link="rod_link_r_1"/>
    <child link="rotary_link_r_2"/>
    <axis xyz="0 0 1"/> 
    <origin rpy="0 0 0" xyz="${ 90* scale_factor} ${-55 * scale_factor} ${-0 * scale_factor} "/>
    <limit effort="100" lower="-1.57" upper="1.57" velocity="1" />
  </joint>

   <link name="rotary_link_r_2">
    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
    <inertial>
      <mass value="${0.0525}" />
      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
    </inertial>
  </link>

  

  <joint name="joint_base_to_rotary_p_2" type="revolute">
  <parent link="rotary_link_p_2"/>
  <child link="base_2"/>
  <origin rpy="0 0 0" xyz="${ -35 * scale_factor} ${-15 * scale_factor} 0"/>
  <axis xyz="1 0 0"/>
  <limit effort="100" lower="-1.57" upper="1.57" velocity="1"/>
</joint>


  
  
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
  
  <link name="base_2">
    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
    <inertial>
      <mass value="${0.0525}" />
      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
    </inertial>
  </link>

</robot>

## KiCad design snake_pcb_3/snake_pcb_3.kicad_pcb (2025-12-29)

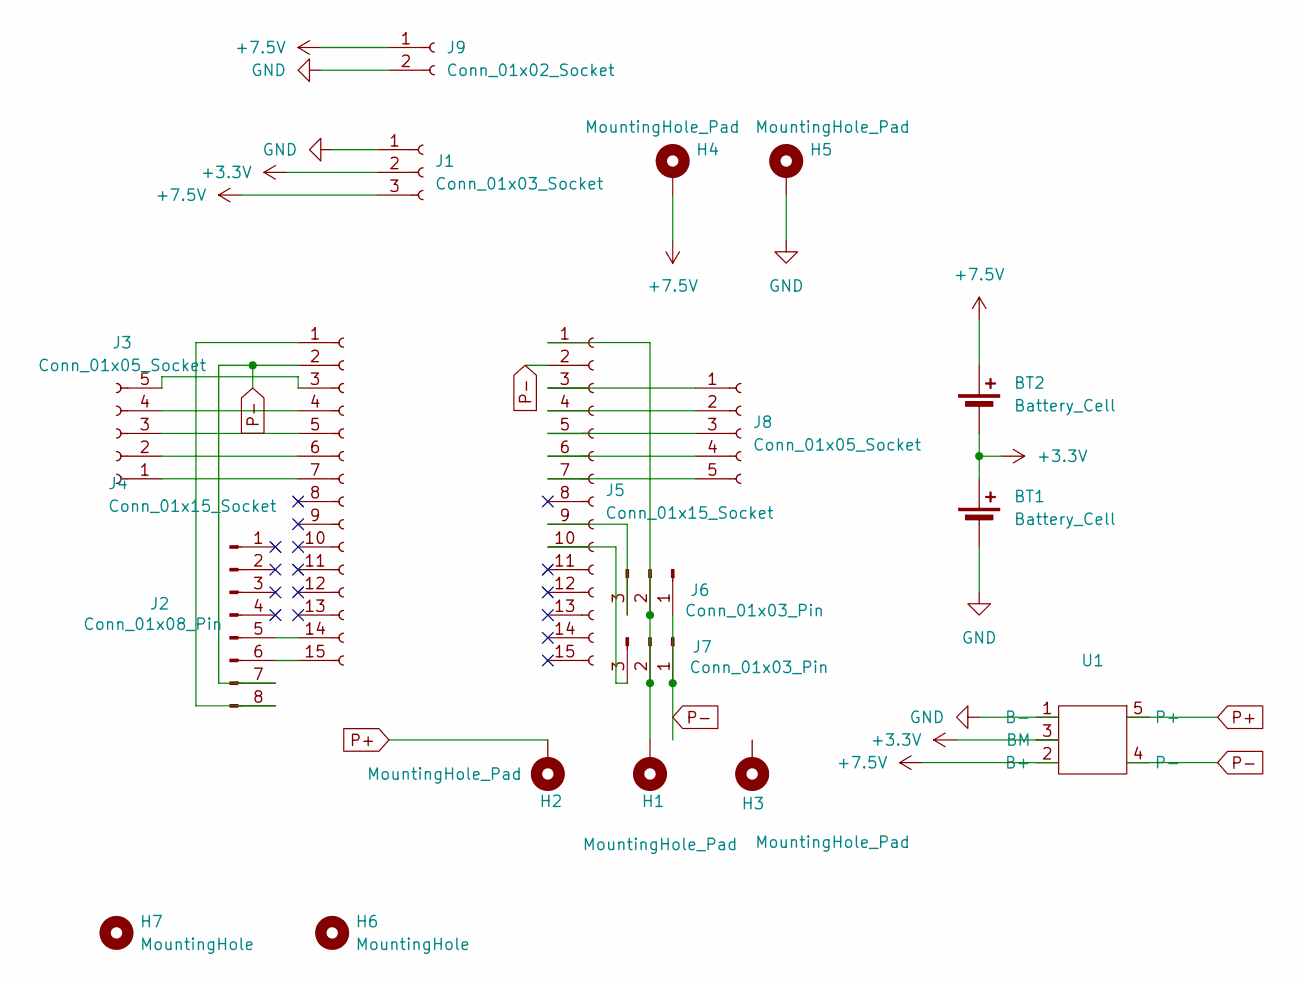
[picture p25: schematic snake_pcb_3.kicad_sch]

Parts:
BT1, BT2: Battery_Cell; BatteryHolder_Keystone_1042_1x18650
H1, H2, H3, H4, H5: MountingHole_Pad; MountingHole_2.2mm_M2_Pad
H6, H7: MountingHole; MountingHole_3.2mm_M3
J1: Conn_01x03_Socket; JST_XH_S3B-XH-A_1x03_P2.50mm_Horizontal
J2: Conn_01x08_Pin; PinHeader_1x08_P2.54mm_Vertical
J3, J8: Conn_01x05_Socket; PinSocket_1x05_P2.54mm_Vertical
J4, J5: Conn_01x15_Socket; PinSocket_1x15_P2.54mm_Vertical
J6, J7: Conn_01x03_Pin; PinHeader_1x03_P2.54mm_Vertical
J9: Conn_01x02_Socket; JST_XH_B2B-XH-AM_1x02_P2.50mm_Vertical
U1: hx-2s-01

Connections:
+3.3V: BT1.1 (+), BT2.2 (-), J1.2, U1.3 (BM)
+7.5V: BT2.1 (+), H4.1, J1.3, J9.1, U1.2 (B+)
GND: BT1.2 (-), H5.1, J1.1, J9.2, U1.1 (B-)
unnamed: J2.5, J4.14
unnamed: J2.6, J4.15
unnamed: J2.8, J4.1
unnamed: J3.1, J4.7
unnamed: J3.2, J4.6
unnamed: J3.3, J4.5
unnamed: J3.4, J4.4
unnamed: J3.5, J4.3
unnamed: H1.1, J5.1, J6.2, J7.2
unnamed: J5.3, J8.1
unnamed: J5.4, J8.2
unnamed: J5.5, J8.3
unnamed: J5.6, J8.4
unnamed: J5.7, J8.5
unnamed: J5.9, J6.3
unnamed: J5.10, J7.3
P+: H2.1, U1.5 (P+)
P-: J2.7, J4.2, J5.2, J6.1, J7.1, U1.4 (P-)

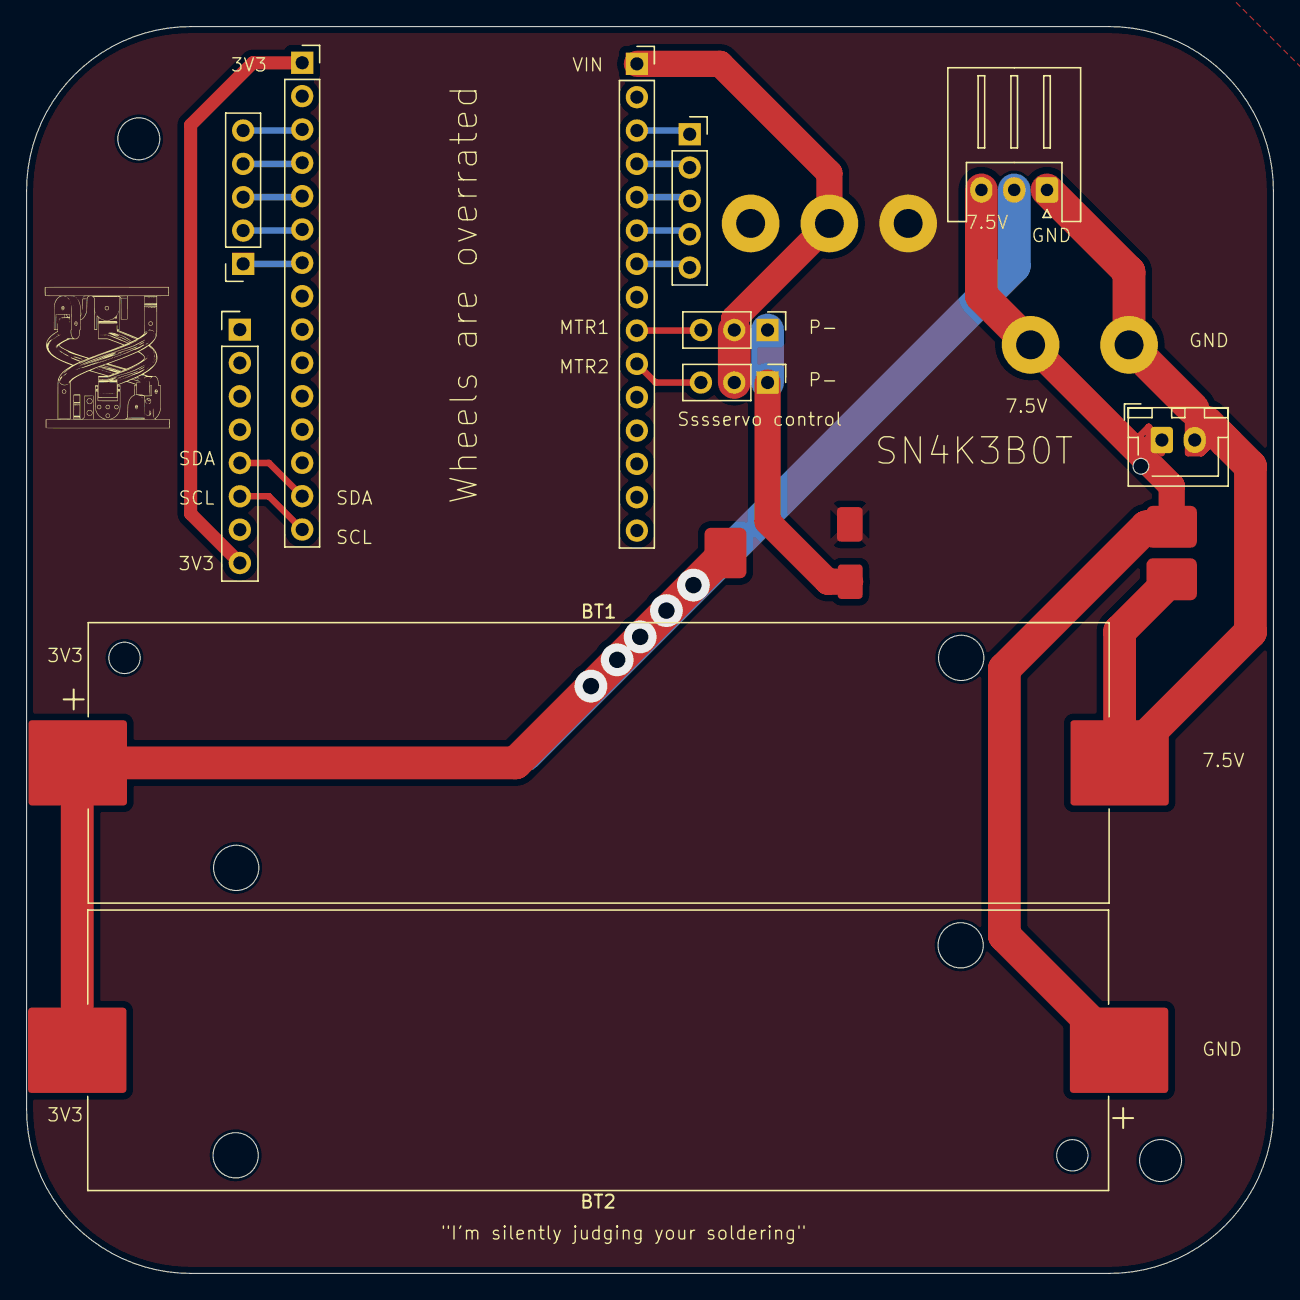
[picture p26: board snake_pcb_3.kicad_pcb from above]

Board: 2 copper layers, 95.0 x 95.0 mm, 19 parts (0 on the bottom side), 21 nets.

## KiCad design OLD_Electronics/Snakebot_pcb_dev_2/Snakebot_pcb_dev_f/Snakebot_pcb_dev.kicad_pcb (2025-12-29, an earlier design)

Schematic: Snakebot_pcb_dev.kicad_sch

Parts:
C1, C8, C10: 22uF; C_0603_1608Metric_Pad1.08x0.95mm_HandSolder
C2, C6, C7, C9, C13, C14, C15: 0.1uF; C_0603_1608Metric_Pad1.08x0.95mm_HandSolder
C3, C11, C12: 1uF; C_0805_2012Metric_Pad1.18x1.45mm_HandSolder
C4, C5: 10uF; C_0805_2012Metric_Pad1.18x1.45mm_HandSolder
C16: 220pF; C_0603_1608Metric_Pad1.08x0.95mm_HandSolder
D1, D2, D3: LED; LED_0805_2012Metric_Pad1.15x1.40mm_HandSolder
H1, H2: MountingHole; MountingHole_3.2mm_M3
J1: Conn_01x04_Socket; JST_EH_S4B-EH_1x04_P2.50mm_Horizontal
J2, J5, J6: Conn_01x02_Socket; JST_EH_S2B-EH_1x02_P2.50mm_Horizontal
J3, J4: Conn_01x03_Socket; JST_EH_B3B-EH-A_1x03_P2.50mm_Vertical
J7, J8: Conn_01x08_Socket; JST_EH_B8B-EH-A_1x08_P2.50mm_Vertical
L1: 6.8uH; L_Bourns_SRN8040TA
R1, R6, R7: 10k; R_0603_1608Metric_Pad0.98x0.95mm_HandSolder
R2, R3, R4: 1K; R_0603_1608Metric_Pad0.98x0.95mm_HandSolder
R5: 50m; R_0603_1608Metric_Pad0.98x0.95mm_HandSolder
R8: 100k; R_0805_2012Metric_Pad1.20x1.40mm_HandSolder
R9, R10: 4.7k; R_0603_1608Metric_Pad0.98x0.95mm_HandSolder
SW1, SW2: SW_Push; SW_Push_1P1T_NO_CK_KSC6xxJ
SW3: SW_SPDT; SW_SPDT_CK_JS102011SAQN
U1: ESP32-WROOM-32E; ESP32-WROOM-32D
U2: AMS1117-3.3; SOT-223-3_TabPin2
U3: MP2615GQ-P; QFN-3x3_MP2615_MNP
U4: MPU-6050; InvenSense_QFN-24_4x4mm_P0.5mm

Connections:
+3.3V: C1.1, C2.1, C5.1, C13.2, C14.2, J7.7, J7.8, J8.1, R1.1, R9.1, R10.1, U1.2 (VDD), U2.2 (VO), U4.8 (VLOGIC), U4.13 (VDD)
+5V: J1.1, SW3.3 (C)
+7.5V: C10.1, J2.1, J3.2, J4.2, R5.2, SW3.1 (A), U3.9 (BATT)
BOOT: C7.1, J7.4, SW2.2, U1.25 (IO0)
EN: C3.2, C6.1, J7.3, J8.7, R1.2, SW1.2, U1.3 (EN)
GND: C1.2, C2.2, C3.1, C4.2, C5.2, C6.2, C7.2, C8.2, C10.2, C11.2, C12.1, C13.1, C14.1, C15.1, C16.2, D1.1 (K), J1.2, J2.2, J3.1, J4.1, J5.2, J6.2, J7.1, J7.2, J8.8, R7.2, R8.1, SW1.1, SW2.1, U1.1 (GND), U1.15 (GND), U1.38 (GND), U1.39 (GND), U2.1 (GND), U3.4 (CELL), U3.5 (SEL), U3.8 (AGND), U3.16 (PGND), U4.1 (CLKIN), U4.9 (AD0), U4.11 (FSYNC), U4.18 (GND)
IO25: J8.4, U1.10 (IO25)
IO26: J8.3, U1.11 (IO26)
IO27: J8.2, U1.12 (IO27)
IO32: J8.6, U1.8 (IO32)
IO33: J8.5, U1.9 (IO33)
MOTOR_H: J3.3, U1.27 (IO16)
MOTOR_V: J4.3, U1.28 (IO17)
unnamed: D1.2 (A), R2.2
unnamed: D2.2 (A), R3.2
unnamed: D2.1 (K), U3.12 (*ACOK)
unnamed: D3.2 (A), R4.2
unnamed: D3.1 (K), U3.11 (*CHGOK)
unnamed: C4.1, R2.1, SW3.2 (B), U2.3 (VI)
unnamed: R8.2, U3.6 (*EN)
unnamed: C9.1, L1.1, U3.15 (BST)
unnamed: L1.2, R5.1, U3.10 (CSP)
unnamed: R6.2, R7.1, U3.13 (NTC)
unnamed: C9.2, U3.1 (SW)
unnamed: C11.1, U3.14 (TMR)
unnamed: C12.2, R6.1, U3.3 (VCC)
unnamed: C16.1, U4.20 (CPOUT)
unnamed: C15.2, U4.10 (REGOUT)
RX: J1.4, U1.34 (RXD0/IO3)
RX2: J7.5, U1.31 (IO19)
SCL: R9.2, U1.36 (IO22), U4.23 (SCL)
SDA: R10.2, U1.33 (IO21), U4.24 (SDA)
TX: J1.3, U1.35 (TXD0/IO1)
TX2: J7.6, U1.30 (IO18)
VCC: C8.1, J5.1, J6.1, R3.1, R4.1, U3.2 (VIN)

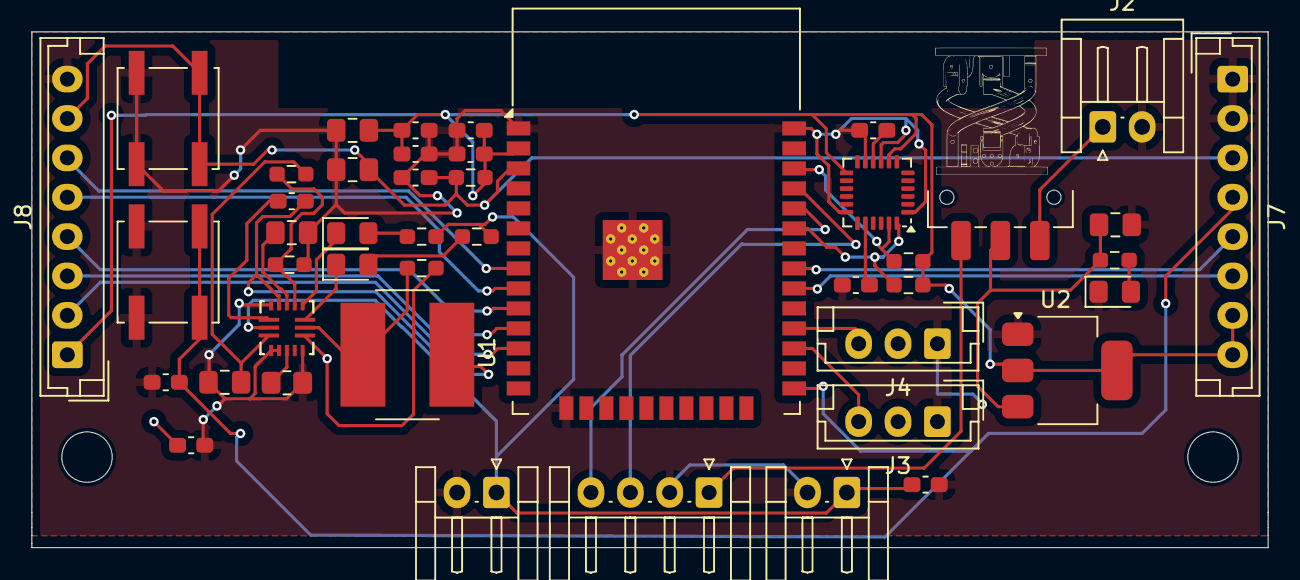
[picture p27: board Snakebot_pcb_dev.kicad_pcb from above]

Board: 2 copper layers, 78.5 x 32.8 mm, 47 parts (0 on the bottom side), 35 nets.

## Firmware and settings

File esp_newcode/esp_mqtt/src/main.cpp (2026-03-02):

#include <Arduino.h> // REQUIRED for PlatformIO
#include <WiFi.h>
#include <PubSubClient.h>
#include <ArduinoJson.h>
#include <ESP32Servo.h>
#include "time.h"

// --- CONFIGURATION ---
const char* ssid = "Snakebot";
const char* password = "12345678";
const char* mqtt_server = "10.52.183.173"; // Updated to your Hotspot IP

const char* THIS_ESP_ID = "ESP_01"; 

const int SERVO_PIN_1 = 32;
const int SERVO_PIN_2 = 33;

// --- MULTITASKING & QUEUE CONFIG ---
#define MAX_QUEUE_SIZE 50 

struct ServoCommand {
  unsigned long long timestamp;
  int angle1;
  int angle2;
  bool isValid;
};

ServoCommand commandQueue[MAX_QUEUE_SIZE];
volatile int queueHead = 0; 
volatile int queueTail = 0; 
volatile int queueCount = 0;
portMUX_TYPE queueMux = portMUX_INITIALIZER_UNLOCKED;

TaskHandle_t NetworkTaskHandle;
TaskHandle_t ServoTaskHandle;

WiFiClient espClient;
PubSubClient client(espClient);
Servo servo1;
Servo servo2;

const char* ntpServer = "pool.ntp.org";
const long  gmtOffset_sec = 0;
const int   daylightOffset_sec = 0;

// ================================================================
//  FUNCTION PROTOTYPES (THE FIX)
//  These tell C++ that these functions exist further down
// ================================================================
void mqttCallback(char* topic, byte* payload, unsigned int length);
void reconnectMQTT();
unsigned long long getCurrentMillis();
void networkTask(void * parameter);
void servoTask(void * parameter);

// ================================================================
//  HELPER FUNCTIONS
// ================================================================

unsigned long long getCurrentMillis() {
  struct timeval tv;
  gettimeofday(&tv, NULL);
  return (unsigned long long)(tv.tv_sec) * 1000 + (unsigned long long)(tv.tv_usec) / 1000;
}

void reconnectMQTT() {
  while (!client.connected()) {
    Serial.print("Connecting to MQTT...");
    String clientId = "ESP32-" + String(THIS_ESP_ID) + "-";
    clientId += String(random(0xffff), HEX);
    
    if (client.connect(clientId.c_str())) {
      Serial.println("Connected");
      client.subscribe("servos/sync_command");
    } else {
      Serial.print("failed, rc=");
      Serial.print(client.state());
      delay(2000);
    }
  }
}

void mqttCallback(char* topic, byte* payload, unsigned int length) {
  StaticJsonDocument<512> doc;
  DeserializationError error = deserializeJson(doc, payload, length);

  if (error) {
    Serial.print("JSON Error: "); Serial.println(error.f_str());
    return;
  }

  if (doc["data"].containsKey(THIS_ESP_ID)) {
    unsigned long long ts = doc["ts"];
    int a1 = doc["data"][THIS_ESP_ID][0];
    int a2 = doc["data"][THIS_ESP_ID][1];

    portENTER_CRITICAL(&queueMux);
    
    int nextTail = (queueTail + 1) % MAX_QUEUE_SIZE;
    if (nextTail != queueHead) {
      commandQueue[queueTail].timestamp = ts;
      commandQueue[queueTail].angle1 = a1;
      commandQueue[queueTail].angle2 = a2;
      commandQueue[queueTail].isValid = true;
      
      queueTail = nextTail;
      queueCount++;
      Serial.printf("Queued cmd for %llu (Total: %d)\n", ts, queueCount);
    } else {
      Serial.println("Queue FULL! Dropping command.");
    }
    
    portEXIT_CRITICAL(&queueMux);
  }
}

// ================================================================
//  TASKS
// ================================================================

void networkTask(void * parameter) {
  WiFi.begin(ssid, password);
  while (WiFi.status() != WL_CONNECTED) {
    delay(500);
    Serial.print(".");
  }
  Serial.println("\nWiFi Connected.");

  configTime(gmtOffset_sec, daylightOffset_sec, ntpServer);
  struct tm timeinfo;
  Serial.print("Syncing Time");
  while(!getLocalTime(&timeinfo)){
    Serial.print(".");
    delay(100);
  }
  Serial.println("\nTime Synced!");

  client.setServer(mqtt_server, 1883);
  client.setCallback(mqttCallback);

  for (;;) {
    if (!client.connected()) {
      reconnectMQTT();
    }
    client.loop(); 
    delay(10); 
  }
}

void servoTask(void * parameter) {
  servo1.attach(SERVO_PIN_1);
  servo2.attach(SERVO_PIN_2);
  servo1.write(90);
  servo2.write(90);
  for (;;) {
    unsigned long long currentMs = getCurrentMillis();
    bool shouldExecute = false;
    ServoCommand cmd;

    portENTER_CRITICAL(&queueMux);
    
    if (queueHead != queueTail) { 
      if (currentMs >= commandQueue[queueHead].timestamp) {
        cmd = commandQueue[queueHead];
        shouldExecute = true;
        queueHead = (queueHead + 1) % MAX_QUEUE_SIZE;
        queueCount--;
      }
    }
    
    portEXIT_CRITICAL(&queueMux);

    if (shouldExecute) {
      Serial.printf("Executing Move: %d, %d at %llu\n", cmd.angle1, cmd.angle2, currentMs);
      servo1.write(cmd.angle1);
      servo2.write(cmd.angle2);
    }

    delay(1);
  }
}

// ================================================================
//  MAIN SETUP & LOOP
// ================================================================

void setup() {
  Serial.begin(115200);

  xTaskCreatePinnedToCore(networkTask, "NetworkTask", 10000, NULL, 1, &NetworkTaskHandle, 0);
  xTaskCreatePinnedToCore(servoTask, "ServoTask", 10000, NULL, 1, &ServoTaskHandle, 1);
}

void loop() {
  vTaskDelete(NULL); 
}

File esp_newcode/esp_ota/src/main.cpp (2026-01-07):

#include <Arduino.h>

#include <WiFi.h>
#include <ESPmDNS.h>
#include <WiFiUdp.h>
#include <ArduinoOTA.h>

const char* ssid = "Snakebot";
const char* password = "12345678";

// LED Logic (Non-blocking so OTA doesn't lag)
const int ledPin = 2; // Built-in LED is usually GPIO 2 on ESP32
unsigned long previousMillis = 0;

// --- CHANGE THIS VALUE TO VERIFY UPDATE ---
// 1000 = Slow Blink (1 second)
// 200  = Fast Blink (0.2 seconds)
const long interval = 1000; 

void setup() {
  Serial.begin(115200);
  Serial.println("Booting");
  
  pinMode(ledPin, OUTPUT);

  // 1. Connect to WiFi
  WiFi.mode(WIFI_STA);
  WiFi.begin(ssid, password);
  while (WiFi.waitForConnectResult() != WL_CONNECTED) {
    Serial.println("Connection Failed! Rebooting...");
    delay(5000);
    ESP.restart();
  }

  // 2. Configure OTA
  // Port defaults to 3232
  // ArduinoOTA.setPort(3232);

  // Hostname defaults to esp3232-[MAC]
  ArduinoOTA.setHostname("esp32-ota-test");

  // No authentication by default
  // ArduinoOTA.setPassword("admin");

  ArduinoOTA
    .onStart([]() {
      String type;
      if (ArduinoOTA.getCommand() == U_FLASH)
        type = "sketch";
      else // U_SPIFFS
        type = "filesystem";

      // NOTE: if updating SPIFFS this would be the place to unmount SPIFFS using SPIFFS.end()
      Serial.println("Start updating " + type);
    })
    .onEnd([]() {
      Serial.println("\nEnd");
    })
    .onProgress([](unsigned int progress, unsigned int total) {
      Serial.printf("Progress: %u%%\r", (progress / (total / 100)));
    })
    .onError([](ota_error_t error) {
      Serial.printf("Error[%u]: ", error);
      if (error == OTA_AUTH_ERROR) Serial.println("Auth Failed");
      else if (error == OTA_BEGIN_ERROR) Serial.println("Begin Failed");
      else if (error == OTA_CONNECT_ERROR) Serial.println("Connect Failed");
      else if (error == OTA_RECEIVE_ERROR) Serial.println("Receive Failed");
      else if (error == OTA_END_ERROR) Serial.println("End Failed");
    });

  ArduinoOTA.begin();

  Serial.println("Ready");
  Serial.print("IP address: ");
  Serial.println(WiFi.localIP());
}

void loop() {
  // CRITICAL: This allows the ESP to listen for update requests
  ArduinoOTA.handle();

  // Non-blocking blink to show the code is running
  unsigned long currentMillis = millis();
  if (currentMillis - previousMillis >= interval) {
    previousMillis = currentMillis;
    int ledState = digitalRead(ledPin);
    digitalWrite(ledPin, !ledState);
  }
}

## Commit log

2024-08-15 Add files via upload
    "fsolve is a local solver that doesn't always guarantee the solution satisfies all constraints, especially when dealing with complex systems of equations and starting points that may lead to a solution outside the desired constraints." ie it CAN and WILL give incorrect points, so different function used here
    [figure_out_snake_v6(Fsolve is kachra).py]
2024-08-22 Add files via upload
    added animating and fixed issue with real angles
    [figure_out_snake_v6.2.py]
2024-08-27 Add files via upload
    Added the PCB schematic as done so far.
    [Snakebot PCB.kicad_sch]
2024-08-27 Add files via upload
    minor changes to schematic including establishing connections between rp2040 and memory. Also added ground and voltage in other places
    [Snakebot PCB.kicad_sch]
2024-09-23 Restructuring Repository
    [snake_robot.urdf]
2024-10-05 Add files via upload
    PCB schematic done, layout in progress.
2024-11-19 Add files via upload
    Arduino code that takes angle from serial monitor and turn servos accordingly.
2024-11-19 Rename Controls/Snake.ino to Controls/Arduino Controller/Snake.ino
2024-11-19 Add files via upload
    To get the initial position of all servos to default at 90 degrees
2024-11-22 Update Snake.ino
    Last iterations had a few bugs
    [Snake.ino]
2024-11-22 Update Snake.ino
    To accommodate the inverted motors
    [Snake.ino]
2025-01-21 Add files via upload
    simplified version of v7, designed specifcally to get the angles for basic urdf simulations
2025-02-25 Add files via upload
    Arduino code that iteratively serially receives and sets servo angles
2025-04-03 Initial commit - uploading snake_robot_harmonic_ws
    [Snakebot.csv, Snakebot.urdf, base_link.STL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]
2025-05-14 Deleted unnecessary folders
    [Snakebot.csv, Snakebot.urdf, base_link.STL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]
2025-05-14 Removed .git directory from mujoco_playground_unitree
    [Snakebot.csv, Snakebot.urdf, base_link.STL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]
2025-05-15 Gymnasium update
    [base_link.STL, rod_1.STL, rod_2.STL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]
2025-05-15 added gymnasium set ups -no RL
    [base_link.STL, rod_1.STL, rod_2.STL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]
2025-08-27 Reorganize project structure and fix MJCF relative path
    [FLEXER_CPG_Sinusoidal_Control_Snake_Robot_Locomotion.py, cpg_snake_control_gui.py, cpg_snake_control_gui_minimal.py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]
2025-12-29 Adding new electronics and mech + restructuring
    [Component1.step, Lithium Battery Capacity Indicator Module.SLDPRT, Lithium Battery Capacity Indicator Module.STEP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]
2026-01-13 added meshes
    [chintu.stl, danda support.stl, danda.stl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]
